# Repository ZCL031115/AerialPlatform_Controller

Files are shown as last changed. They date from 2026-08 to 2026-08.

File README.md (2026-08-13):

# AerialPlatform_Controller

STM32F103-based hardware safety controller for an aerial work platform. The
repository contains separate ECU (vehicle-side) and PCU (ground-side) firmware
projects migrated to the STM32 HAL library.

## Projects

- `ECU/`: vehicle-side controller, LoRa command handling, relay control, RC522
  card authentication, BMP280 pressure/height monitoring, and diagnostics.
- `PCU/`: ground-side controller, emergency-stop input, LoRa bridge, and
  diagnostics.

Both projects include STM32CubeMX `.ioc` files, Makefiles, STM32 HAL drivers,
and Windows host-side unit tests.

## Serial Interfaces

| Interface | Baud rate | Purpose |
| --- | ---: | --- |
| USART1 | 115200, 8N1 | Diagnostic output |
| USART2 | 115200, 8N1 | PC/external controller bridge |
| USART3 | 9600, 8N1 | MCU to LoRa module |

The two LoRa modules must also be configured for a local UART rate of 9600 baud
and matching radio channel, address, and air-data settings.

## Safety Commands

- `0x87`: emergency stop. The PCU forwards it over LoRa; the ECU enters the
  emergency-stop state, de-energizes the relay, and forwards the byte to its
  USART2 test interface.
- `0x26`: restore. The PCU accepts and forwards it only while the local
  emergency-stop input is inactive.

The PCU starts in a latched safe state. A valid restore command is required
before normal operation.

## Build

With GNU Arm Embedded Toolchain and Make available:

```powershell
make -j16 -f Makefile GCC_PATH=<arm-none-eabi-toolchain>/bin
```

Run the host tests on Windows with Visual Studio C/C++ Build Tools installed:

```powershell
cmd /c Tests\host\run_tests.cmd
```

Run the commands separately from the `ECU` and `PCU` directories.

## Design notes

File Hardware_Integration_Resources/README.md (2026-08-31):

# Aerial Platform Hardware Integration Resources

This folder contains the design files needed to integrate the ECU, PCU,
RS232-to-CAN interface, and enclosure. It is intended for the PCB and
mechanical-design collaborators.

## Contents

- `Final_Relay_Board/`: final Altium project for the relay-equipped board.
- `Final_NoRelay_Board/`: final Altium project for the board without the relay.
- `RS232_CAN_Adapter/`: Altium project for the RS232-to-CAN adapter.
- `Module_References/`: UWB footprint and datasheet, LoRa datasheet, RC522
  documentation, project overview, and the ECU/PCU pin assignment.

## File selection

The Altium project, schematic, PCB, library, output-job, and reference PDF
files are included where available. History folders, project logs, preview
files, compiled firmware, temporary files, and personal authentication data
are intentionally excluded.

## Mechanical-design notes

Use the `.PcbDoc` files for the board outline, mounting holes, connector
locations, and keep-out regions. Use the UWB `.DXF` and `.PcbLib` files for
the UWB module footprint. Before the enclosure is frozen, confirm the actual
battery, cable bend radius, external connectors, relay clearance, and NFC
card-reading window against the physical samples.

## Electrical-design notes

The two LoRa modules use the same radio parameters and a 9600-baud local UART.
The MCU pin assignment and current interface roles are documented in the
included pin-assignment file. Treat the final relay-equipped board as the ECU
reference and the final no-relay board as the PCU reference unless the
hardware team identifies a newer revision.

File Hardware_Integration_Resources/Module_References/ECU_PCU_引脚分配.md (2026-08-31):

# ECU 与 PCU 引脚分配

本文整理自现有急停工程、高空车测试工程，以及已确认的局部原理图。MCU 为 STM32F103ZE。

## 1. 角色定义

| 单元 | 安装位置/职责 | 关键功能 |
|---|---|---|
| PCU | 地面侧安全控制单元 | 急停回路输入、LoRa 发令、UWB（高空车测试工程）、控制数据转发 |
| ECU | 高空车车载执行单元 | LoRa 收令、NFC/RC522 授权、安全继电器控制、姿态/环境传感器 |

## 2. 两端共用引脚

| MCU 引脚 | 外设/功能 | 信号方向 | 说明 |
|---|---|---|---|
| PA9 | USART1_TX | MCU -> 外部 | 调试/串口 1 发送 |
| PA10 | USART1_RX | 外部 -> MCU | 调试/串口 1 接收 |
| PA2 | USART2_TX | MCU -> 外部 | 串口 2 发送；若该板装有 SP3232，则经其转换为 RS-232 电平 |
| PA3 | USART2_RX | 外部 -> MCU | 串口 2 接收；若该板装有 SP3232，则由其从 RS-232 电平转换回来 |
| PB10 | USART3_TX | MCU -> LoRa RX | LoRa 模块本地 UART 发送 |
| PB11 | USART3_RX | LoRa TX -> MCU | LoRa 模块本地 UART 接收 |
| PE0 | LoRa MD0 | MCU -> LoRa | LoRa 工作模式控制 |
| PE1 | LoRa MD1 | MCU -> LoRa | LoRa 工作模式控制 |
| PB6 | BMP280 SCL | 双向 | 原工程使用 GPIO 模拟 I2C；HAL 可改用 I2C1_SCL |
| PB7 | BMP280 SDA | 双向 | 原工程使用 GPIO 模拟 I2C；HAL 可改用 I2C1_SDA |
| PA0 | KEY1 | 外部 -> MCU | 板载按键 1 |
| PC13 | KEY2 | 外部 -> MCU | 板载按键 2 |

### LoRa 模式脚

| 模式 | PE0 / MD0 | PE1 / MD1 | 用途 |
|---|---:|---:|---|
| 正常收发 | 0 | 0 | LoRa 透明传输 |
| 配置/休眠 | 1 | 1 | 以手册规定的 UART 参数读写模块配置 |

LoRa 的 AUX 未接入 MCU。模式切换、发送完成和参数写入必须按模块手册使用保守延时，不能依赖 AUX 判定忙闲。

## 3. ECU 专用引脚

| MCU 引脚 | 外设/功能 | 信号方向 | 当前软件含义 |
|---|---|---|---|
| PD6 | 安全继电器控制 | MCU -> 继电器驱动 | 程序初始化为高；收到急停后输出低。继电器触点的实际断开/吸合极性仍应以继电器驱动原理图为准。 |
| PA4 | RC522 SDA/SS | MCU -> RC522 | RC522 片选 |
| PB8 | RC522 RST | MCU -> RC522 | RC522 复位 |
| PB13 | RC522 SCK / SPI2_SCK | MCU -> RC522 | 原工程 GPIO 模拟 SPI；HAL 可迁移为 SPI2 时钟 |
| PB14 | RC522 MISO / SPI2_MISO | RC522 -> MCU | 原工程 GPIO 模拟 SPI；HAL 可迁移为 SPI2 MISO |
| PB15 | RC522 MOSI / SPI2_MOSI | MCU -> RC522 | 原工程 GPIO 模拟 SPI；HAL 可迁移为 SPI2 MOSI |
| PA11 | ADXL345 SCL | 双向 | GPIO 模拟 I2C 时钟；与 USB/CAN1 默认复用冲突 |
| PA12 | ADXL345 SDA | 双向 | GPIO 模拟 I2C 数据；与 USB/CAN1 默认复用冲突 |

## 4. PCU 专用引脚

| MCU 引脚 | 外设/功能 | 信号方向 | 当前软件含义 |
|---|---|---|---|
| PD6 | 急停回路状态 | 外部 -> MCU | EL817 光耦输出；低电平表示 VIN2 存在/回路正常，高电平表示 VIN2 丢失/急停。 |
| PC10 | UART4_TX | MCU -> UWB | 仅高空车测试工程的 UWB 串口 |
| PC11 | UART4_RX | UWB -> MCU | 仅高空车测试工程的 UWB 串口 |

### PCU 急停输入电路（VIN2 - EL817 - PD6）

| VIN2 状态 | EL817 输出晶体管 | PD6 电平 | PCU 动作 |
|---|---|---:|---|
| VIN2 正常存在 | 导通 | 低 | 正常；此前若处于急停状态则发送 `0x26` 恢复命令 |
| VIN2 消失、急停按钮断开或线路断线 | 截止 | 高（R54 10 kOhm 上拉） | 发送 `0x87` 急停命令 |

输入侧由 R53（1 kOhm）限制 EL817 LED 电流，输出侧由 R54（10 kOhm）上拉至 3.3 V。因此 PD6 虽在旧代码中配置为浮空输入，硬件上实际已有外部上拉，电平不会悬空。

注意：局部原理图两侧均标注 `GND`。若两者属于同一电源网络，EL817 不构成完整的电气隔离，仅提供输入电平转换和一定的抗干扰/保护作用。

## 5. 急停命令与执行链路

```text
PCU 急停回路断开
  -> VIN2 消失，PD6 由 R54 上拉为高
  -> PCU USART3 / LoRa 发送 0x87
  -> ECU USART3 / LoRa 接收 0x87
  -> ECU PD6 输出低
  -> 继电器释放，切断外部设备的控制或使能回路
```

| 命令字节 | PCU 来源 | ECU 当前处理 |
|---:|---|---|
| `0x87` | PCU PD6 读高（急停） | 将 ECU 继电器控制脚 PD6 拉低 |
| `0x26` | PCU PD6 从高恢复到低 | 将 ECU 继电器控制脚 PD6 拉高并恢复通信状态 |
| `0x86` | PCU KEY2 | ECU 置通信断开标志；现有工程中继电器断开语句被注释，不能视为急停保护。 |

急停并不会让 ECU MCU 停机；ECU 需要持续运行，才能保持安全状态并接收后续的人工复位/恢复流程。

## 6. HAL 迁移建议

| 功能 | HAL 外设/模式 |
|---|---|
| LoRa | USART3：PB10/PB11；PE0/PE1 为 GPIO 推挽输出 |
| PCU 急停 | PD6 为 GPIO 输入；使用外部 R54 上拉，GPIO 可配置为 `GPIO_NOPULL` |
| ECU 继电器 | PD6 为 GPIO 推挽输出；上电默认状态应按继电器驱动电路验证，安全设计建议默认保持断开 |
| BMP280 | 优先 I2C1：PB6/PB7 |
| RC522 | 优先 SPI2：PB13/PB14/PB15，另保留 PA4 片选、PB8 复位 |
| ADXL345 | 保留 PA11/PA12 GPIO 模拟 I2C，或改线并与 BMP280 共用 I2C1 |
| UWB | UART4：PC10/PC11（PCU 高空车功能） |

## 7. 整合工程必须保留的安全约束

1. 急停状态应锁存；按钮释放不应直接自动吸合 ECU 继电器，应要求明确人工复位及全部安全条件满足。
2. ECU 应监测 PCU 的 LoRa 心跳超时。PCU 掉电或无线链路丢失时，ECU 应释放继电器。
3. LoRa 急停命令应升级为带帧头、地址、序号、CRC、重复发送和确认的协议，不能只依赖单字节匹配。
4. ECU 继电器输出的真实安全极性必须结合继电器驱动与触点原理图、万用表实测确认后再固化。

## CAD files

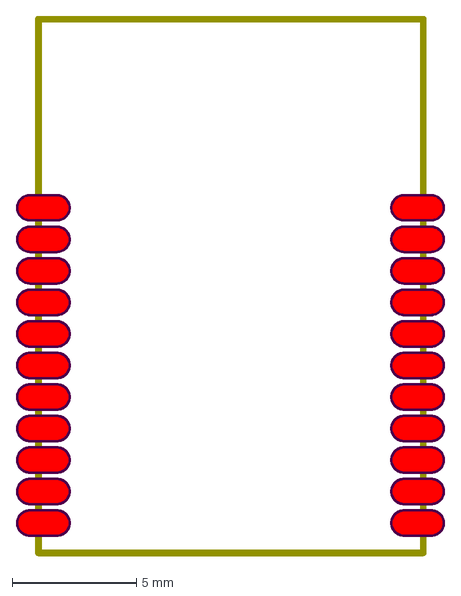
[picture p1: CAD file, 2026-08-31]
Hardware_Integration_Resources/Module_References/UWB/MK8000TR7.9-GC 封装.DXF
17.3 x 21.8 mm

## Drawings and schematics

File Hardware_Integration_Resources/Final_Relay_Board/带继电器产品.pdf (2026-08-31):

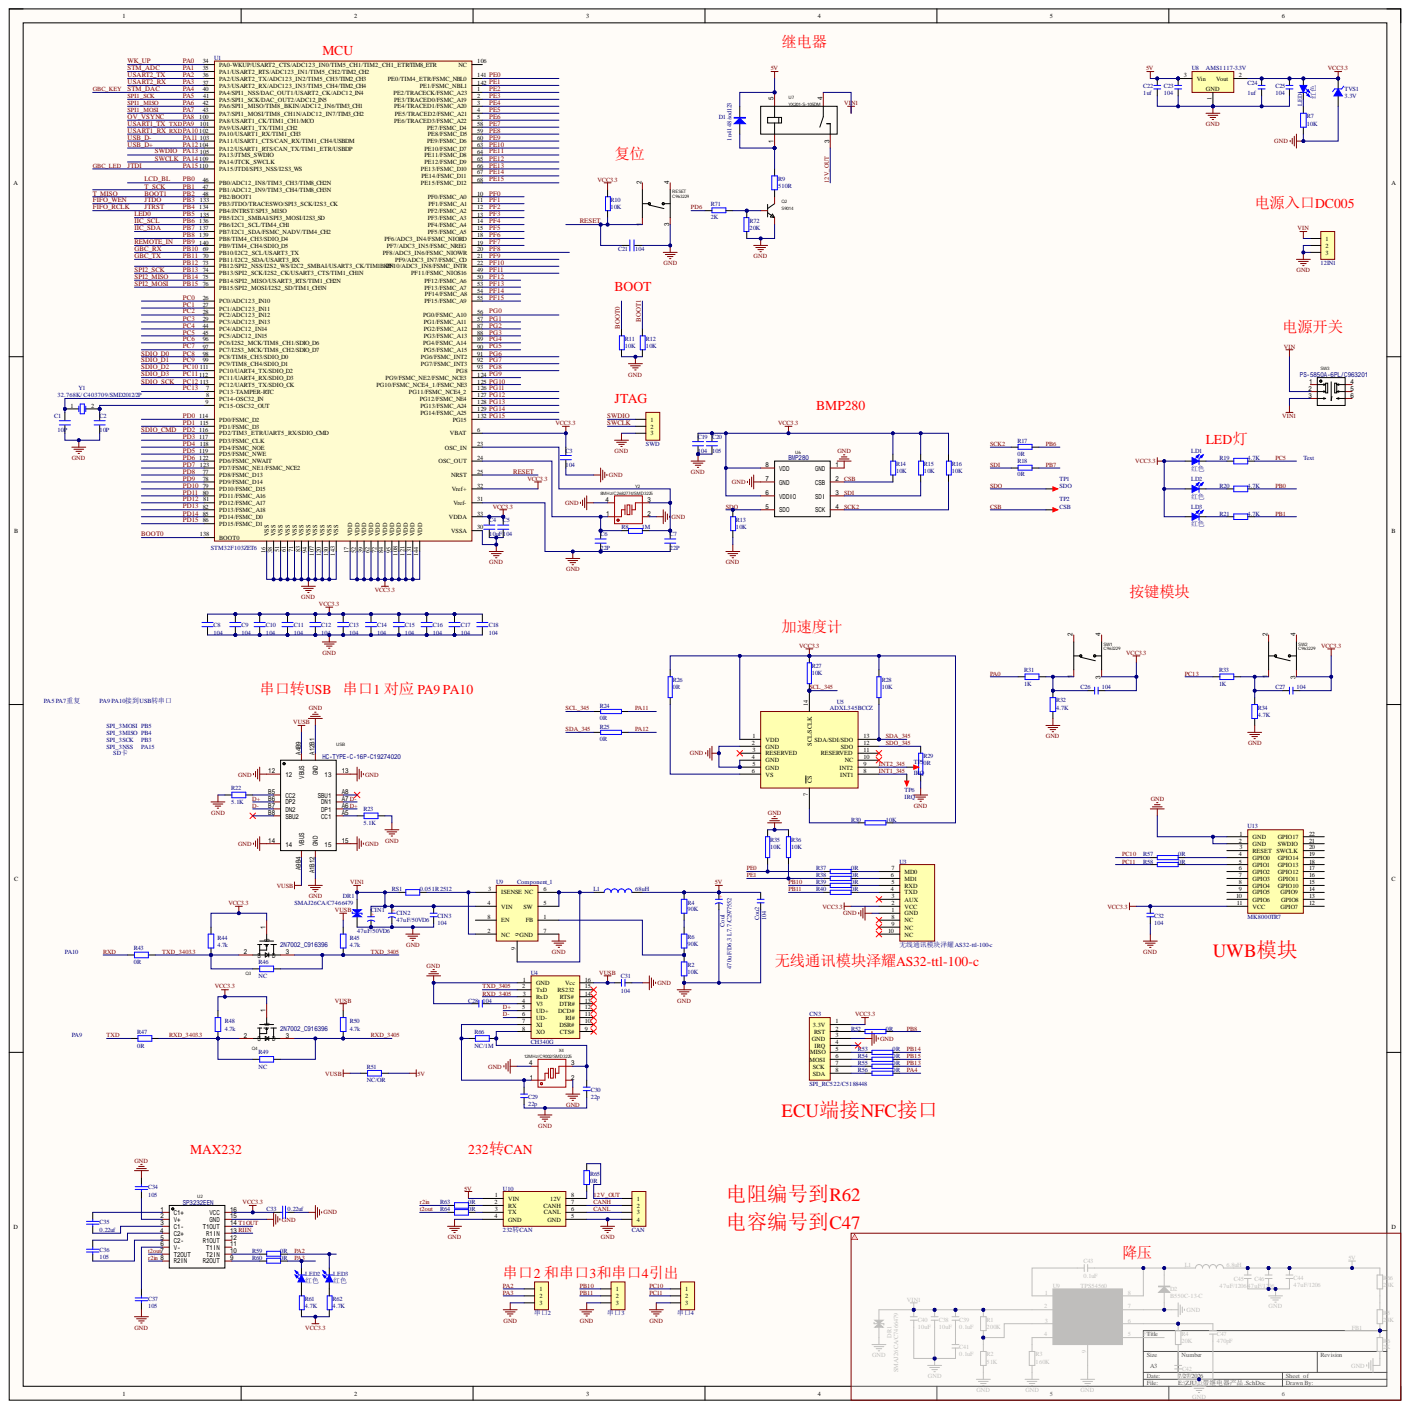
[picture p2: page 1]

GND 2 | SDO_345 | GND

VS 6 | INT1_345

Size A3 | Number C42 | Revision

File: E:\ZJU\..\带继电器产品.SchDoc | Drawn By:

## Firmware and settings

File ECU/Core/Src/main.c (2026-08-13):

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
/* Includes ------------------------------------------------------------------*/
#include "main.h"
#include "usart.h"
#include "gpio.h"

/* USER CODE BEGIN Includes */
#include "ecu_app_hal.h"
#include "ecu_diagnostics.h"
#include "ecu_monitor_hal.h"

/* USER CODE END Includes */


void SystemClock_Config(void);
/**
 * @brief  The application entry point.
 * @retval int
 */
int main(void)
{

  /* MCU Configuration--------------------------------------------------------*/

  /* Reset of all peripherals, Initializes the Flash interface and the Systick. */
  HAL_Init();

  /* Configure the system clock */
  SystemClock_Config();
  
  /* Initialize all configured peripherals */
  MX_GPIO_Init();
  MX_USART1_UART_Init();
  MX_USART3_UART_Init();
  /* USER CODE BEGIN 2 */
  ECU_Diagnostics_Init();
  {
    const bool app_ok = ECU_App_HAL_Init();
    const bool monitor_ok = ECU_Monitor_HAL_Init();

    ECU_Diagnostics_ReportInit(app_ok, monitor_ok);
    if (!app_ok)
    {
      Error_Handler();
    }
  }

  /* USER CODE END 2 */

  /* Infinite loop */
  /* USER CODE BEGIN WHILE */
  while (1)
  {
    /* USER CODE END WHILE */

    /* USER CODE BEGIN 3 */
    const EcuApp *app = ECU_App_HAL_GetState();
    ECU_App_HAL_Process();
    ECU_Monitor_HAL_Process(
        HAL_GetTick(),
        (app != NULL) ? app->control.state : ECU_CONTROL_SAFE_STARTUP);
    ECU_Diagnostics_Process(HAL_GetTick());
  }
  /* USER CODE END 3 */
}

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


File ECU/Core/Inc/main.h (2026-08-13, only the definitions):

#define KEY2_Pin GPIO_PIN_13
#define KEY2_GPIO_Port GPIOC
#define KEY1_Pin GPIO_PIN_0
#define KEY1_GPIO_Port GPIOA
#define RC522_CS_Pin GPIO_PIN_4
#define RC522_CS_GPIO_Port GPIOA
#define RC522_SCK_Pin GPIO_PIN_13
#define RC522_SCK_GPIO_Port GPIOB
#define RC522_MISO_Pin GPIO_PIN_14
#define RC522_MISO_GPIO_Port GPIOB
#define RC522_MOSI_Pin GPIO_PIN_15
#define RC522_MOSI_GPIO_Port GPIOB
#define BMP_SCL_Pin GPIO_PIN_6
#define BMP_SCL_GPIO_Port GPIOB
#define BMP_SDA_Pin GPIO_PIN_7
#define BMP_SDA_GPIO_Port GPIOB
#define RC522_RST_Pin GPIO_PIN_8
#define RC522_RST_GPIO_Port GPIOB
#define LoRa_MD0_Pin GPIO_PIN_0
#define LoRa_MD0_GPIO_Port GPIOE
#define LoRa_MD1_Pin GPIO_PIN_1
#define LoRa_MD1_GPIO_Port GPIOE

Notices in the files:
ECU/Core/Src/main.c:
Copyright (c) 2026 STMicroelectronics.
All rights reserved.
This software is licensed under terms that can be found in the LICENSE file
